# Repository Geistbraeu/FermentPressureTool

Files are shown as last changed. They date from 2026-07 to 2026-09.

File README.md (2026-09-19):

🌐 **English** | [Русский](README.ru.md)

# FermentPressureTool

A device for monitoring and controlling the fermentation process with real-time pressure and temperature measurement.

## 📋 Project Overview

**FermentPressureTool** is an ESP32-based IoT device designed for precise fermentation condition control. It reads pressure and temperature inside a fermentation vessel, uploads data to cloud services, and controls a pressure relief valve.

<p align="center">
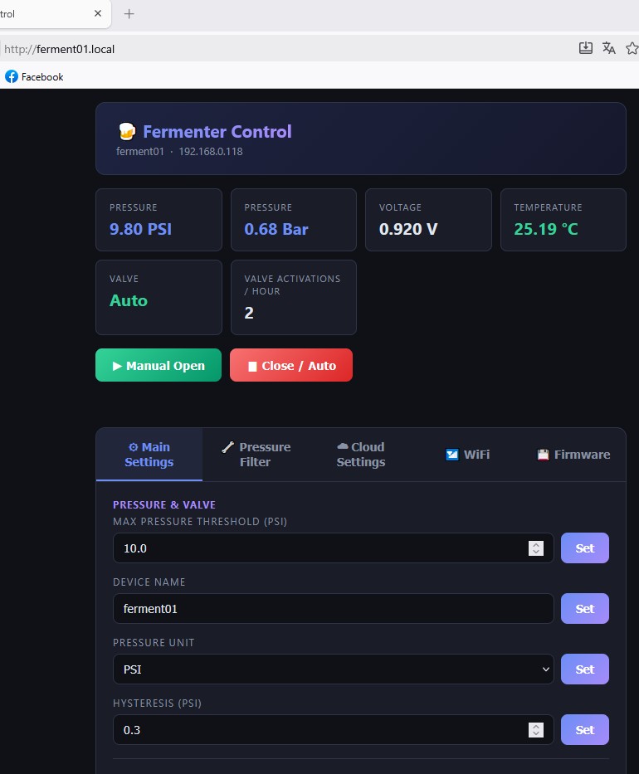
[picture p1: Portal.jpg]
FermentPressureTool web portal
   FermentPressureTool device
</p>

### Key Features

- 📊 **Pressure monitoring** — analog pressure sensor reading via ADC
- 🌡️ **Temperature measurement** — DS18B20 sensor support over OneWire
- 📡 **Cloud integration** — data upload to:
  - **Brewfather** (homebrewing platform)
  - **ThingSpeak** (IoT platform)
  - **Custom HTTP API** (flexible integration)
- 🖥️ **Web interface** — browser-based control and monitoring
- 🔧 **Configuration portal** — WiFi setup without reflashing
- 📱 **OLED display** — alternating pressure and temperature display (SSD1306, 128×64)
- 🤖 **Multithreading** — parallel execution of sensor and network operations
- 💾 **Persistent settings** — stored in Preferences/NVS

## 🛠️ Hardware

### Microcontroller
- **ESP32-DevKit** — WiFi-enabled dual-core microcontroller

### Sensors and Modules
- **Pressure sensor** — analog, connected to `GPIO34` (ADC1_CH6)
- **External ADC (optional)** — ADS1115 on the same I2C bus as the OLED (address `0x48`, pressure input `A0`)
- **Temperature sensor** — DS18B20 (OneWire)
  - DATA: `GPIO4`
  - 4.7 kΩ pull-up resistor required between DATA and VCC
- **OLED display** — SSD1306 128×64 (I2C, address 0x3C)
- **Solenoid valve** — controlled via `GPIO27`

### Connections
- Serial (UART) at 115200 baud for debugging
- CH340 USB-UART converter for programming

### Pressure ADC selection

The web settings provide a choice between the built-in ESP32 ADC and an external ADS1115.
The ESP32 mode keeps the existing voltage divider on `GPIO34`. In ADS1115 mode, connect the
pressure sensor directly to `A0`; the divider is not used because this input supports the
sensor's 0.5-4.5 V signal range. Connect `VDD`, `GND`, `SDA`, and `SCL` to the board and tie
`ADDR` to `GND` for address `0x48`. The ADS1115 and ESP32 must share ground. Do not exceed the
ADS1115 supply voltage or its absolute input limits.

### Recommended settings for external ADC

When using the external ADS1115, the following settings are recommended for stable and responsive
pressure readings:

- Median Sample Count (odd, 3-31): `5`
- Median Sample Delay (ms): `10`
- Update Interval (ms): `50`

These values reduce sensor noise while keeping the UI and pressure control responsive enough for
fermentation monitoring.

When using the external ADS1115, the adaptive filter can be disabled if the ADC already provides a
stable signal and additional smoothing is not needed.

## 📁 Project Structure

```
FermentPressureTool/
├── src/
│   ├── main.cpp                 # Entry point, initialization
│   ├── config.h                 # Central constants (pins, parameters)
│   ├── Settings.h/cpp           # Persistent settings management
│   ├── CloudManager.h/cpp       # Cloud provider coordination
│   ├── ConfigPortal.h/cpp       # WiFi configuration portal
│   ├── web_server.h/cpp         # REST API and web interface
│   ├── RuntimeState.h           # Shared state between cores
│   ├── debug.h                  # Debug macros
│   ├── html_template.h          # Web UI HTML
│   ├── cloud/
│   │   ├── CloudProvider.h      # Base provider interface
│   │   ├── BrewfatherProvider.h/cpp
│   │   ├── ThingSpeakProvider.h/cpp
│   │   └── CustomHTTPProvider.h/cpp
│   └── device/
│       ├── DisplayManager.h/cpp      # OLED display management
│       ├── SensorManager.h/cpp       # Sensor reading (pressure, temperature)
│       └── SolenoidController.h/cpp  # Valve control
├── include/                     # User libraries
├── lib/                         # External libraries
├── test/                        # Tests
├── platformio.ini               # PlatformIO configuration
└── README.md                    # This file
```

## 🔌 Software Components

### CloudManager
Coordinates data upload to cloud platforms. Supports multiple simultaneous providers.

### ConfigPortal
WiFi configuration portal for initial setup and reconfiguration without reflashing.

### SensorManager
- ADC initialization and eFuse-based calibration
- Filtered pressure reading (average of N samples)
- DS18B20 temperature reading over OneWire

### DisplayManager
Manages the SSD1306 OLED display, alternating between pressure and temperature. The switch interval is configurable via the web interface.

### WebServer
REST API for:
- Retrieving current sensor data
- Controlling the valve
- Changing system parameters
- Triggering cloud uploads

### SolenoidController
Controls the solenoid valve for pressure relief.

## 🚀 Getting Started

### Requirements
- **PlatformIO** — embedded build system
- **VS Code** with the PlatformIO extension
- **CH340 driver** — for USB programming

### Dependencies
Declared in `platformio.ini`:
```
adafruit/Adafruit SSD1306 @ ^2.5.9
adafruit/Adafruit GFX Library @ ^1.11.9
adafruit/Adafruit BusIO @ ^1.14.5
paulstoffregen/OneWire @ ^2.3.8
milesburton/DallasTemperature @ ^4.0.4
```

### Build and Flash

1. **Open the project in VS Code**
   ```bash
   code d:\Projects\FermentPressureTool
   ```

2. **Connect the ESP32 via USB**

3. **Select the environment in PlatformIO**
   - Choose `esp32s` from the available environments

4. **Build the project**
   ```bash
   pio run -e esp32s
   ```

5. **Upload the firmware**
   ```bash
   pio run -e esp32s --target upload
   ```

6. **Open the serial monitor**
   ```bash
   pio device monitor -e esp32s
   ```

## ⚙️ Configuration

### Build Flags
Debug flags defined in `platformio.ini`:
- `APP_DEBUG_SERIAL=0` — debug level (0 = disabled)

### Hardware Pins (`src/config.h`)
All pins are defined centrally in `config.h`. Edit the values before building as needed.

### Network Parameters
- **Hostname**: `ferment01` (accessible as `ferment01.local`)
- **Web server port**: 80
- **UART baud rate**: 115200

### Cloud Integrations
Configure API keys and settings via the configuration portal or web interface:
- **Brewfather API Key**
- **ThingSpeak Channel ID and API Key**
- **Custom HTTP URL endpoint**

### OLED and Sensors
- Pressure and temperature are shown alternately on the OLED.
- The switch interval is configurable in the web interface; default is 3 seconds.
- If the temperature sensor is disconnected, only pressure is shown.
- If the pressure sensor is not connected, the display shows `Disconnected` and cloud uploads are skipped.

## 🌐 Cloud Integration

### Brewfather
Integration with the popular homebrewing platform. Sends pressure and temperature data.

### ThingSpeak
IoT platform for data storage and visualization. Supports measurement history and charts.

### Custom HTTP API
Flexible integration with any HTTP API to send data to a custom backend.

## 📊 REST API

### Get Sensor Data
```
GET /api
```

Response:
```json
{
  "pressure": 1.5,
  "temperature": 22.5,
  "voltage": 2.3,
  "pressureConnected": true,
  "tempConnected": true
}
```

### Control the Valve
```
POST /api
Body: cmd=manual_on
```

### Cloud Upload
Cloud uploads are performed automatically in the firmware's main loop and are skipped if the pressure sensor is disconnected.

## 🔄 Multithreading Architecture

The system uses two tasks running on separate ESP32 cores:
- **Core 1**: Sensor operations (reading sensors, valve control)
- **Core 0**: Network operations (WiFi, cloud requests, web server)

Synchronization is handled through the `RuntimeState` structure using semaphores.

## 🐛 Debugging

Debug output is sent to UART when enabled:

```cpp
DBG("Debug message here");
```

View the output in the serial monitor.

---

<div align="center">

  <p>
    <strong>FermentPressureTool</strong><br>
    ESP32-based fermentation pressure and temperature monitor
  </p>

  <p>
    <strong>Version</strong> 1.2.6 · <strong>Updated</strong> 2026-09-20
  </p>

  <p>
    Built with PlatformIO for ESP32 • Pressure control • Cloud integration
  </p>

</div>

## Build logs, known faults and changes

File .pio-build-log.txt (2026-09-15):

Processing esp32s (platform: espressif32 @ ^6.4.0; board: esp32dev; framework: arduino)
--------------------------------------------------------------------------------
Verbose mode can be enabled via `-v, --verbose` option
CONFIGURATION: https://docs.platformio.org/page/boards/espressif32/esp32dev.html
PLATFORM: Espressif 32 (6.13.0) > Espressif ESP32 Dev Module
HARDWARE: ESP32 240MHz, 320KB RAM, 4MB Flash
DEBUG: Current (cmsis-dap) External (cmsis-dap, esp-bridge, esp-prog, iot-bus-jtag, jlink, minimodule, olimex-arm-usb-ocd, olimex-arm-usb-ocd-h, olimex-arm-usb-tiny-h, olimex-jtag-tiny, tumpa)
PACKAGES: 
 - framework-arduinoespressif32 @ 3.20017.241212+sha.dcc1105b 
 - tool-esptoolpy @ 2.41100.0 (4.11.0) 
 - toolchain-xtensa-esp32 @ 8.4.0+2021r2-patch5
LDF: Library Dependency Finder -> https://bit.ly/configure-pio-ldf
LDF Modes: Finder ~ chain, Compatibility ~ soft
Found 39 compatible libraries
Scanning dependencies...
Dependency Graph
|-- Adafruit SSD1306 @ 2.5.17
|-- Adafruit GFX Library @ 1.12.6
|-- Adafruit BusIO @ 1.17.4
|-- Adafruit ADS1X15 @ 2.6.2
|-- OneWire @ 2.3.8
|-- DallasTemperature @ 4.0.6
|-- DNSServer @ 2.0.0
|-- WebServer @ 2.0.0
|-- WiFi @ 2.0.0
|-- Preferences @ 2.0.0
|-- WiFiClientSecure @ 2.0.0
|-- Wire @ 2.0.0
|-- ESPmDNS @ 2.0.0
|-- Update @ 2.0.0
Building in release mode
Compiling .pio\build\esp32s\src\ConfigPortal.cpp.o
Compiling .pio\build\esp32s\src\Settings.cpp.o
Compiling .pio\build\esp32s\src\cloud\BrewfatherProvider.cpp.o
Compiling .pio\build\esp32s\src\cloud\CustomHTTPProvider.cpp.o
Compiling .pio\build\esp32s\src\cloud\ThingSpeakProvider.cpp.o
Compiling .pio\build\esp32s\src\device\DisplayManager.cpp.o
Compiling .pio\build\esp32s\src\device\SensorManager.cpp.o
Compiling .pio\build\esp32s\src\device\SolenoidController.cpp.o
Compiling .pio\build\esp32s\src\main.cpp.o
Compiling .pio\build\esp32s\src\web_server.cpp.o
Building .pio\build\esp32s\bootloader.bin
Generating partitions .pio\build\esp32s\partitions.bin
esptool.py v4.11.0
Creating esp32 image...
Merged 1 ELF section
Successfully created esp32 image.
Compiling .pio\build\esp32s\libf83\Wire\Wire.cpp.o
Compiling .pio\build\esp32s\lib5a8\SPI\SPI.cpp.o
Compiling .pio\build\esp32s\lib5de\Adafruit BusIO\Adafruit_BusIO_Register.cpp.o
Archiving .pio\build\esp32s\lib5a8\libSPI.a
Archiving .pio\build\esp32s\libf83\libWire.a
Compiling .pio\build\esp32s\lib5de\Adafruit BusIO\Adafruit_GenericDevice.cpp.o
Compiling .pio\build\esp32s\lib5de\Adafruit BusIO\Adafruit_I2CDevice.cpp.o
Compiling .pio\build\esp32s\lib5de\Adafruit BusIO\Adafruit_SPIDevice.cpp.o
Compiling .pio\build\esp32s\libc0d\Adafruit GFX Library\Adafruit_GFX.cpp.o
Compiling .pio\build\esp32s\libc0d\Adafruit GFX Library\Adafruit_GrayOLED.cpp.o
Archiving .pio\build\esp32s\lib5de\libAdafruit BusIO.a
Compiling .pio\build\esp32s\libc0d\Adafruit GFX Library\Adafruit_SPITFT.cpp.o
Compiling .pio\build\esp32s\libc0d\Adafruit GFX Library\glcdfont.c.o
Compiling .pio\build\esp32s\lib6a2\Adafruit SSD1306\Adafruit_SSD1306.cpp.o
Compiling .pio\build\esp32s\libc8a\Adafruit ADS1X15\Adafruit_ADS1X15.cpp.o
Compiling .pio\build\esp32s\lib591\OneWire\OneWire.cpp.o
Archiving .pio\build\esp32s\libc0d\libAdafruit GFX Library.a
Compiling .pio\build\esp32s\lib5f8\DallasTemperature\DallasTemperature.cpp.o
Archiving .pio\build\esp32s\lib6a2\libAdafruit SSD1306.a
Compiling .pio\build\esp32s\libef0\WiFi\WiFi.cpp.o
platformio.exe : .pio/libdeps/esp32s/OneWire/OneWire.cpp:599:22: warning: extra
 tokens at end of #undef directive
At line:1 char:79
+ ... ipts\platformio.exe'; & $platformio run *> .pio-build-log.txt; $exitC ...
+                           ~~~~~~~~~~~~~~~~~~~~~~~~~~~~~~~~~~~~~~~
    + CategoryInfo          : NotSpecified: (.pio/libdeps/es...undef directive 
   :String) [], RemoteException
    + FullyQualifiedErrorId : NativeCommandError
 
 #  undef noInterrupts() {portMUX_TYPE mux = portMUX_INITIALIZER_UNLOCKED;portE
NTER_CRITICAL(&mux)
                      ^
.pio/libdeps/esp32s/OneWire/OneWire.cpp:600:20: warning: extra tokens at end of
 #undef directive
 #  undef interrupts() portEXIT_CRITICAL(&mux);}
                    ^
Archiving .pio\build\esp32s\libc8a\libAdafruit ADS1X15.a
Compiling .pio\build\esp32s\libef0\WiFi\WiFiAP.cpp.o
Archiving .pio\build\esp32s\lib591\libOneWire.a
Compiling .pio\build\esp32s\libef0\WiFi\WiFiClient.cpp.o
Archiving .pio\build\esp32s\lib5f8\libDallasTemperature.a
Compiling .pio\build\esp32s\libef0\WiFi\WiFiGeneric.cpp.o
Compiling .pio\build\esp32s\libef0\WiFi\WiFiMulti.cpp.o
Compiling .pio\build\esp32s\libef0\WiFi\WiFiSTA.cpp.o
Compiling .pio\build\esp32s\libef0\WiFi\WiFiScan.cpp.o
Compiling .pio\build\esp32s\libef0\WiFi\WiFiServer.cpp.o
Compiling .pio\build\esp32s\libef0\WiFi\WiFiUdp.cpp.o
Compiling .pio\build\esp32s\lib0c5\DNSServer\DNSServer.cpp.o
Compiling .pio\build\esp32s\lib226\FS\FS.cpp.o
Compiling .pio\build\esp32s\lib226\FS\vfs_api.cpp.o
Archiving .pio\build\esp32s\libef0\libWiFi.a
Archiving .pio\build\esp32s\lib0c5\libDNSServer.a
Compiling .pio\build\esp32s\lib395\WebServer\Parsing.cpp.o
Compiling .pio\build\esp32s\lib395\WebServer\WebServer.cpp.o
Compiling .pio\build\esp32s\lib395\WebServer\detail\mimetable.cpp.o
Compiling .pio\build\esp32s\lib156\Preferences\Preferences.cpp.o
Archiving .pio\build\esp32s\lib226\libFS.a
Compiling .pio\build\esp32s\lib383\WiFiClientSecure\WiFiClientSecure.cpp.o
Compiling .pio\build\esp32s\lib383\WiFiClientSecure\esp_crt_bundle.c.o
Archiving .pio\build\esp32s\lib156\libPreferences.a
Archiving .pio\build\esp32s\lib395\libWebServer.a
Compiling .pio\build\esp32s\lib383\WiFiClientSecure\ssl_client.cpp.o
Compiling .pio\build\esp32s\lib0ca\ESPmDNS\ESPmDNS.cpp.o
Compiling .pio\build\esp32s\lib797\Update\HttpsOTAUpdate.cpp.o
Compiling .pio\build\esp32s\lib797\Update\Updater.cpp.o
Compiling .pio\build\esp32s\FrameworkArduino\Esp.cpp.o
Archiving .pio\build\esp32s\lib383\libWiFiClientSecure.a
Archiving .pio\build\esp32s\lib0ca\libESPmDNS.a
Compiling .pio\build\esp32s\FrameworkArduino\FirmwareMSC.cpp.o
Compiling .pio\build\esp32s\FrameworkArduino\FunctionalInterrupt.cpp.o
Compiling .pio\build\esp32s\FrameworkArduino\HWCDC.cpp.o
Compiling .pio\build\esp32s\FrameworkArduino\HardwareSerial.cpp.o
Archiving .pio\build\esp32s\lib797\libUpdate.a
Compiling .pio\build\esp32s\FrameworkArduino\IPAddress.cpp.o
Compiling .pio\build\esp32s\FrameworkArduino\IPv6Address.cpp.o
Compiling .pio\build\esp32s\FrameworkArduino\MD5Builder.cpp.o
Compiling .pio\build\esp32s\FrameworkArduino\Print.cpp.o
Compiling .pio\build\esp32s\FrameworkArduino\Stream.cpp.o
Compiling .pio\build\esp32s\FrameworkArduino\StreamString.cpp.o
Compiling .pio\build\esp32s\FrameworkArduino\Tone.cpp.o
Compiling .pio\build\esp32s\FrameworkArduino\USB.cpp.o
Compiling .pio\build\esp32s\FrameworkArduino\USBCDC.cpp.o
Compiling .pio\build\esp32s\FrameworkArduino\USBMSC.cpp.o
Compiling .pio\build\esp32s\FrameworkArduino\WMath.cpp.o
Compiling .pio\build\esp32s\FrameworkArduino\WString.cpp.o
Compiling .pio\build\esp32s\FrameworkArduino\base64.cpp.o
Compiling .pio\build\esp32s\FrameworkArduino\cbuf.cpp.o
Compiling .pio\build\esp32s\FrameworkArduino\esp32-hal-adc.c.o
Compiling .pio\build\esp32s\FrameworkArduino\esp32-hal-bt.c.o
Compiling .pio\build\esp32s\FrameworkArduino\esp32-hal-cpu.c.o
Compiling .pio\build\esp32s\FrameworkArduino\esp32-hal-dac.c.o
Compiling .pio\build\esp32s\FrameworkArduino\esp32-hal-gpio.c.o
Compiling .pio\build\esp32s\FrameworkArduino\esp32-hal-i2c-slave.c.o
Compiling .pio\build\esp32s\FrameworkArduino\esp32-hal-i2c.c.o
Compiling .pio\build\esp32s\FrameworkArduino\esp32-hal-ledc.c.o
Compiling .pio\build\esp32s\FrameworkArduino\esp32-hal-matrix.c.o
Compiling .pio\build\esp32s\FrameworkArduino\esp32-hal-misc.c.o
Compiling .pio\build\esp32s\FrameworkArduino\esp32-hal-psram.c.o
Compiling .pio\build\esp32s\FrameworkArduino\esp32-hal-rgb-led.c.o
Compiling .pio\build\esp32s\FrameworkArduino\esp32-hal-rmt.c.o
Compiling .pio\build\esp32s\FrameworkArduino\esp32-hal-sigmadelta.c.o
Compiling .pio\build\esp32s\FrameworkArduino\esp32-hal-spi.c.o
Compiling .pio\build\esp32s\FrameworkArduino\esp32-hal-time.c.o
Compiling .pio\build\esp32s\FrameworkArduino\esp32-hal-timer.c.o
Compiling .pio\build\esp32s\FrameworkArduino\esp32-hal-tinyusb.c.o
Compiling .pio\build\esp32s\FrameworkArduino\esp32-hal-touch.c.o
Compiling .pio\build\esp32s\FrameworkArduino\esp32-hal-uart.c.o
Compiling .pio\build\esp32s\FrameworkArduino\firmware_msc_fat.c.o
Compiling .pio\build\esp32s\FrameworkArduino\libb64\cdecode.c.o
Compiling .pio\build\esp32s\FrameworkArduino\libb64\cencode.c.o
Compiling .pio\build\esp32s\FrameworkArduino\main.cpp.o
Compiling .pio\build\esp32s\FrameworkArduino\stdlib_noniso.c.o
Compiling .pio\build\esp32s\FrameworkArduino\wiring_pulse.c.o
Compiling .pio\build\esp32s\FrameworkArduino\wiring_shift.c.o
Archiving .pio\build\esp32s\libFrameworkArduino.a
Linking .pio\build\esp32s\firmware.elf
Retrieving maximum program size .pio\build\esp32s\firmware.elf
Checking size .pio\build\esp32s\firmware.elf
Advanced Memory Usage is available via "PlatformIO Home > Project Inspect"
RAM:   [==        ]  17.5% (used 57492 bytes from 327680 bytes)
Flash: [========  ]  82.8% (used 1085913 bytes from 1310720 bytes)
Building .pio\build\esp32s\firmware.bin with action:
  "$PYTHONEXE" "$OBJCOPY" --chip esp32 elf2image --flash_mode ${__get_board_flash_mode(__env__)} --flash_freq ${__get_board_f_image(__env__)} --flash_size 4MB --elf-sha256-offset 0xb0 -o $TARGET $SOURCES
Building .pio\build\esp32s\firmware.bin
esptool.py v4.11.0
Creating esp32 image...
Merged 27 ELF sections
Successfully created esp32 image.
_copy_versioned_firmware_bin([".pio\build\esp32s\firmware.bin"], [".pio\build\esp32s\firmware.elf"])
======================== [SUCCESS] Took 130.24 seconds ========================

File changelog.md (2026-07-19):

# Changelog

## 1.2.2 - 2026-07-19

### Fixed
- OLED header now shows the configured device name (`devName`) from settings instead of the compile-time default hostname.
- mDNS now starts with the configured device name, so access via `http://<devName>.local/` works as expected after boot.
- When `devName` is changed in web settings, mDNS is restarted immediately and HTTP service is re-registered, so the new `.local` name applies without reflashing.

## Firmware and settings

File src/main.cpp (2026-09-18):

#include <Arduino.h>
#include <WiFi.h>
#include <Wire.h>
#include <esp_adc_cal.h>
#include <ESPmDNS.h>
#include "config.h"
#include "ConfigPortal.h"
#include "web_server.h"
#include "CloudManager.h"
#include "Settings.h"
#include "RuntimeState.h"
#include "debug.h"
#include "device/DisplayManager.h"
#include "device/SensorManager.h"
#include "device/SolenoidController.h"

// Глобальные переменные для обмена данными между ядрами
RuntimeState runtimeState;

// Прототипы функций
void sensorTask(void *pvParameters);
void networkTask(void *pvParameters);
void processSampledData();

void setup() {
  Serial.begin(NetworkConfig::SERIAL_BAUD_RATE);   
  while (!Serial); 

  Wire.begin();
  DBG("I2C bus initialized");

  // Настройка АЦП и чтение калибровки из eFuse
  sensorManager.initAdc(&runtimeState.adc_chars);

  // Инициализация OLED
  displayManager.init();

  // Инициализация Wi-Fi через ConfigPortal
  ConfigPortal::begin();

  // Инициализация клапана
  solenoidController.init();

  // Инициализация mDNS
  const String mdnsHost = wifiSettings.devName.isEmpty() ? String(NetworkConfig::HOSTNAME) : wifiSettings.devName;
  if (!MDNS.begin(mdnsHost.c_str())) {
    DBG("mDNS ERROR");
  } else {
    DBG("mDNS responder started: " + mdnsHost + ".local");
    MDNS.addService("http", "tcp", NetworkConfig::WEBSERVER_PORT);
  }
 
  // Чтение настроек
  settings.load();

  // Инициализация DS18B20
  sensorManager.initTempSensor(settings.useTempSensor);

  // Создаем мьютекс для защиты общих данных
  runtimeState.dataMutex = xSemaphoreCreateMutex();
  runtimeState.settingsMutex = xSemaphoreCreateMutex();
  if (runtimeState.dataMutex == NULL || runtimeState.settingsMutex == NULL) {
    Serial.println("FATAL: mutex creation failed");
    for (;;) {
      delay(1000);
    }
  }

  // Инициализация веб-сервера
  initWebServer();

  // Задача для чтения сенсора (Core 1)
  xTaskCreatePinnedToCore(
    sensorTask,
    "SensorTask",
    TaskConfig::SENSOR_TASK_STACK_SIZE,
    NULL,
    TaskConfig::SENSOR_TASK_PRIORITY,
    NULL,
    TaskConfig::SENSOR_TASK_CORE
  );

  // Задача для Wi-Fi и облаков (Core 0)
  xTaskCreatePinnedToCore(
    networkTask,
    "NetworkTask",
    TaskConfig::NETWORK_TASK_STACK_SIZE,
    NULL,
    TaskConfig::NETWORK_TASK_PRIORITY,
    NULL,
    TaskConfig::NETWORK_TASK_CORE
  );

  DBG("\n--- Система запущена на двух ядрах ---");
}

void loop() {
  // Пустой цикл, всё работает в задачах FreeRTOS
  vTaskDelete(NULL); 
}

void processSampledData() {
  bool useTempSensor = false;
  float maxPressureThreshold = 0.0f;
  float hysteresis = 0.0f;
  float tempOffset = 0.0f;
  if (xSemaphoreTake(runtimeState.settingsMutex, TaskConfig::MUTEX_TIMEOUT_TICKS) == pdTRUE) {
    useTempSensor = settings.useTempSensor;
    maxPressureThreshold = settings.maxPressureThreshold;
    hysteresis = settings.hysteresis;
    tempOffset = settings.tempOffset;
    xSemaphoreGive(runtimeState.settingsMutex);
  }

  bool isTempConnected = false;
  float t = sensorManager.readTemperature(useTempSensor, tempOffset, &isTempConnected);
  runtimeState.isTempSensorConnected = isTempConnected;

  if (xSemaphoreTake(runtimeState.dataMutex, TaskConfig::MUTEX_TIMEOUT_TICKS) == pdTRUE) {
    if (runtimeState.hasSampledData) {
      runtimeState.currentVoltage = runtimeState.sampledVoltage;
      runtimeState.currentPressure = runtimeState.sampledPressure;
      runtimeState.isPressureSensorConnected = runtimeState.currentVoltage >= SensorConfig::PRESSURE_DISCONNECTED_THRESHOLD_V;
      runtimeState.currentTemp = t;
      runtimeState.isDataReady = true;

        if (runtimeState.manualOverride &&
          (unsigned long)(millis() - runtimeState.manualStartTime) > ControlConfig::MANUAL_OVERRIDE_TIMEOUT_MS) {
          runtimeState.manualOverride = false;
      }

      if (runtimeState.manualOverride) {
          solenoidController.applyState(true, runtimeState.manualOn, runtimeState.currentPressure, maxPressureThreshold, hysteresis);
      } else {
          solenoidController.applyState(false, false, runtimeState.currentPressure, maxPressureThreshold, hysteresis);
      }
    }
    xSemaphoreGive(runtimeState.dataMutex);
  }
}

// --- ЛОГИКА СЕНСОРА (Core 1) ---
void sensorTask(void *pvParameters) {
  unsigned long lastProcessAt = 0;

  for (;;) {
    unsigned int sampleCount = ControlConfig::DEFAULT_MEDIAN_SAMPLE_COUNT;
    unsigned long medianSampleDelayMs = ControlConfig::DEFAULT_MEDIAN_SAMPLE_DELAY_MS;
    unsigned long updateIntervalMs = ControlConfig::DEFAULT_UPDATE_INTERVAL_MS;
    uint8_t pressureAdc = SensorConfig::PRESSURE_ADC_ESP32;
    bool adaptiveFilterEnabled = true;
    float offsetVoltage = SensorConfig::PRESSURE_OFFSET_DEFAULT;
    float adaptiveAlphaMin = ControlConfig::DEFAULT_ADAPTIVE_ALPHA_MIN;
    float adaptiveAlphaMax = ControlConfig::DEFAULT_ADAPTIVE_ALPHA_MAX;
    float adaptiveDeltaRefPsi = ControlConfig::DEFAULT_ADAPTIVE_DELTA_REF_PSI;
    float adaptiveJitterDeadbandPsi = ControlConfig::DEFAULT_ADAPTIVE_JITTER_DEADBAND_PSI;
    if (xSemaphoreTake(runtimeState.settingsMutex, TaskConfig::MUTEX_TIMEOUT_TICKS) == pdTRUE) {
      sampleCount = settings.medianSampleCount;
      medianSampleDelayMs = settings.medianSampleDelayMs;
      updateIntervalMs = settings.updateIntervalMs;
      pressureAdc = settings.pressureAdc;
      adaptiveFilterEnabled = settings.adaptiveFilterEnabled;
      offsetVoltage = settings.offsetVoltage;
      adaptiveAlphaMin = settings.adaptiveAlphaMin;
      adaptiveAlphaMax = settings.adaptiveAlphaMax;
      adaptiveDeltaRefPsi = settings.adaptiveDeltaRefPsi;
      adaptiveJitterDeadbandPsi = settings.adaptiveJitterDeadbandPsi;
      xSemaphoreGive(runtimeState.settingsMutex);
    }

    bool isValveOpen = digitalRead(HardwareConfig::SOLENOID_PIN) == HIGH;
    SensorReading reading = sensorManager.readFilteredPressure(sampleCount,
                                   medianSampleDelayMs,
                                   pressureAdc,
                                   offsetVoltage,
                                   isValveOpen,
                                   adaptiveFilterEnabled,
                                                               adaptiveAlphaMin,
                                                               adaptiveAlphaMax,
                                                               adaptiveDeltaRefPsi,
                                                               adaptiveJitterDeadbandPsi,
                                   &runtimeState.adc_chars);

    // 4. Непрерывно публикуем фильтрованные значения в RuntimeState
    if (xSemaphoreTake(runtimeState.dataMutex, TaskConfig::MUTEX_TIMEOUT_TICKS) == pdTRUE) {
      runtimeState.sampledVoltage = reading.voltage;
      runtimeState.sampledPressure = reading.pressure;
      runtimeState.hasSampledData = true;
      xSemaphoreGive(runtimeState.dataMutex);
    }

    // 5. Периодическая обработка sampled данных по updateIntervalMs
    unsigned long now = millis();
    if (lastProcessAt == 0 || (now - lastProcessAt) >= updateIntervalMs) {
      processSampledData();
      lastProcessAt = now;
    }
  }
}

// --- ЛОГИКА СЕТИ (Core 0) ---
void networkTask(void *pvParameters) {
  initCloud();

  for (;;) {
    float vLocal = 0.0, pLocal = 0.0, tLocal = 0.0;
    uint32_t valveActivationsPerHourLocal = 0;
    bool isTempSensorConnected = false;
    bool isPressureSensorConnected = false;
    bool ready = false;
    int pressureUnit = 0;
    float maxPressureThreshold = 0.0f;
    bool useTempSensor = false;
    unsigned long oledMetricSwitchSeconds = ControlConfig::DEFAULT_OLED_METRIC_SWITCH_SECONDS;

    // Проверка подключения
    if (WiFi.status() != WL_CONNECTED) {
      ConfigPortal::connect();
    }

    // Получаем копию данных и статус готовности
    if (xSemaphoreTake(runtimeState.dataMutex, TaskConfig::MUTEX_TIMEOUT_TICKS) == pdTRUE) {
      vLocal = runtimeState.currentVoltage;
      pLocal = runtimeState.currentPressure;
      tLocal = runtimeState.currentTemp;
      valveActivationsPerHourLocal = runtimeState.valveActivationsPerHour;
      isTempSensorConnected = runtimeState.isTempSensorConnected;
      isPressureSensorConnected = runtimeState.isPressureSensorConnected;
      ready = runtimeState.isDataReady;
      xSemaphoreGive(runtimeState.dataMutex);
    }

    if (xSemaphoreTake(runtimeState.settingsMutex, TaskConfig::MUTEX_TIMEOUT_TICKS) == pdTRUE) {
      pressureUnit = settings.pressureUnit;
      maxPressureThreshold = settings.maxPressureThreshold;
      useTempSensor = settings.useTempSensor;
      oledMetricSwitchSeconds = settings.oledMetricSwitchSeconds;
      xSemaphoreGive(runtimeState.settingsMutex);
    }

    // Обновление дисплея
    String ipStr = "Connecting...";
    if (WiFi.status() == WL_CONNECTED) {
      ipStr = WiFi.localIP().toString();
    }
    float pBar = pLocal * SensorConfig::PSI_TO_BAR;
    displayManager.update(ipStr,
                          vLocal,
                          pBar,
                          pressureUnit,
                          maxPressureThreshold,
                          tLocal,
                          useTempSensor,
                          isTempSensorConnected,
                          oledMetricSwitchSeconds);

    // Выполняем отправку только если данные уже были считаны сенсором
    if (ready && isPressureSensorConnected) {
      sendDataToThingSpeak(vLocal, pLocal, pBar, tLocal, valveActivationsPerHourLocal);
      sendDataToBrewfather(vLocal, pLocal, tLocal, valveActivationsPerHourLocal);
      sendDataViaCustomHTTP(vLocal, pLocal, pBar, tLocal, valveActivationsPerHourLocal);
    }
    unsigned long updateIntervalMs = ControlConfig::DEFAULT_UPDATE_INTERVAL_MS;
    if (xSemaphoreTake(runtimeState.settingsMutex, TaskConfig::MUTEX_TIMEOUT_TICKS) == pdTRUE) {
      updateIntervalMs = settings.updateIntervalMs;
      xSemaphoreGive(runtimeState.settingsMutex);
    }
    vTaskDelay(pdMS_TO_TICKS(updateIntervalMs));
  }
}

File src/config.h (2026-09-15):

#ifndef CONFIG_H
#define CONFIG_H

#include <cstddef>
#include <cstdint>

#include <freertos/FreeRTOS.h>

/**
 * FermentPreassureTool - Centralized Configuration
 * All hardware, sensor, and system constants in one place
 */

// ==================== HARDWARE PINS ====================
namespace HardwareConfig {
  // Solenoid relay control
  constexpr int SOLENOID_PIN = 27;

  // Pressure sensor (ADC)
  constexpr int ADC_PRESSURE_PIN = 34;  // ADC1_CH6

  // Temperature sensor (DS18B20 OneWire)
  constexpr int TEMP_SENSOR_PIN = 4;
}

// ==================== DISPLAY (OLED SSD1306) ====================
namespace DisplayConfig {
  constexpr int SCREEN_WIDTH = 128;
  constexpr int SCREEN_HEIGHT = 64;
  constexpr int OLED_RESET_PIN = -1;
  constexpr uint8_t OLED_I2C_ADDRESS = 0x3C;

  // Display layout coordinates (Y positions)
  constexpr int LAYOUT_Y_HOSTNAME = 0;
  constexpr int LAYOUT_Y_STATUS = 15;
  constexpr int LAYOUT_Y_IP = 20;
  constexpr int LAYOUT_Y_PRESSURE = 28;
  constexpr int LAYOUT_Y_TEMP = 35;
  constexpr int LAYOUT_Y_VOLTAGE = 42;
  constexpr int LAYOUT_Y_MANUAL = 52;

  // Display layout coordinates (X positions)
  constexpr int LAYOUT_X_LEFT = 0;
  constexpr int LAYOUT_X_CENTER = 85;
}

// ==================== SENSOR CALIBRATION ====================
namespace SensorConfig {
  constexpr uint8_t PRESSURE_ADC_ESP32 = 0;
  constexpr uint8_t PRESSURE_ADC_ADS1115 = 1;

  constexpr uint8_t ADS1115_I2C_ADDRESS = 0x48;
  constexpr uint8_t ADS1115_PRESSURE_CHANNEL = 0;

  // DS18B20 disconnect sentinel handling
  constexpr float TEMP_DISCONNECTED_C = -127.0;
  constexpr float PRESSURE_DISCONNECTED_THRESHOLD_V = 0.3f;

  // Pressure sensor calibration
  constexpr float PRESSURE_OFFSET_DEFAULT = 0.515;  // Volts
  constexpr float PRESSURE_VOLTAGE_RANGE = 4.0;      // Volts (4.5V - 0.5V)
  constexpr float PRESSURE_PSI_RANGE = 100.0;        // PSI

  // Voltage divider
  constexpr float ADC_VOLTAGE_DIVIDER = 1.4545455;

  // Unit conversions
  constexpr float PSI_TO_BAR = 0.0689476;

  // ADC settings
  // Note: ADC types don't support constexpr, use direct enum values
  // ADC_ATTEN_DB_12 and ADC_WIDTH_BIT_12 are defined in ESP32 Arduino framework
  constexpr uint32_t ADC_VREF = 1100;  // mV
}

// ==================== SAMPLING & CONTROL ====================
namespace ControlConfig {
  // Median filter
  constexpr unsigned int MAX_MEDIAN_SAMPLES = 31;
  constexpr unsigned int MIN_MEDIAN_SAMPLES = 3;

  // Adaptive pressure filter defaults
  constexpr float DEFAULT_ADAPTIVE_ALPHA_MIN = 0.03f;
  constexpr float DEFAULT_ADAPTIVE_ALPHA_MAX = 0.70f;
  constexpr float DEFAULT_ADAPTIVE_DELTA_REF_PSI = 1.0f;
  constexpr float DEFAULT_ADAPTIVE_JITTER_DEADBAND_PSI = 0.05f;

  // Manual solenoid override timeout
  constexpr unsigned long MANUAL_OVERRIDE_TIMEOUT_MS = 10000;  // 10 seconds

  // Default sampling intervals (configurable via web UI)
  constexpr unsigned long DEFAULT_UPDATE_INTERVAL_MS = 200;
  constexpr unsigned int DEFAULT_MEDIAN_SAMPLE_COUNT = 5;
  constexpr unsigned long DEFAULT_MEDIAN_SAMPLE_DELAY_MS = 10;
  constexpr unsigned long DEFAULT_OLED_METRIC_SWITCH_SECONDS = 3;
}

// ==================== NETWORK & mDNS ====================
namespace NetworkConfig {
  constexpr const char* HOSTNAME = "ferment01";
    // HOSTNAME will be used as: WiFi.setHostname(HOSTNAME) and MDNS.begin(HOSTNAME)
  constexpr int WEBSERVER_PORT = 80;
  constexpr int MDNS_PORT = 53;

  // Serial communication
  constexpr unsigned long SERIAL_BAUD_RATE = 115200;
}

// ==================== CLOUD INTEGRATION ====================
namespace CloudConfig {
  // ThingSpeak
  constexpr const char* THINGSPEAK_SERVER = "api.thingspeak.com";
  constexpr int THINGSPEAK_PORT = 443;  // HTTPS
  constexpr unsigned long THINGSPEAK_DEFAULT_INTERVAL_SEC = 120;

  // Brewfather
  constexpr const char* BREWFATHER_SERVER = "log.brewfather.net";
  constexpr int BREWFATHER_PORT = 443;  // HTTPS
  constexpr unsigned long BREWFATHER_DEFAULT_INTERVAL_MIN = 15;

  // Custom HTTP
  constexpr int CUSTOM_HTTP_PORT_HTTP = 80;
  constexpr int CUSTOM_HTTP_PORT_HTTPS = 443;
  constexpr unsigned long CUSTOM_HTTP_DEFAULT_INTERVAL_SEC = 60;
  constexpr size_t CUSTOM_HTTP_MAX_SERVER_LEN = 64;
  constexpr size_t CUSTOM_HTTP_MAX_PATH_LEN = 128;
  constexpr size_t CUSTOM_HTTP_MAX_BODY_LEN = 512;
  constexpr size_t CUSTOM_HTTP_MAX_KEY_LEN = 128;
}

// ==================== FREERTOS TASK CONFIGURATION ====================
namespace TaskConfig {
  // Sensor task (Core 1)
  constexpr int SENSOR_TASK_STACK_SIZE = 4096;
  constexpr int SENSOR_TASK_PRIORITY = 1;
  constexpr int SENSOR_TASK_CORE = 1;

  // Network task (Core 0)
  constexpr int NETWORK_TASK_STACK_SIZE = 8192;
  constexpr int NETWORK_TASK_PRIORITY = 1;
  constexpr int NETWORK_TASK_CORE = 0;

  // Mutex timeout
  const TickType_t MUTEX_TIMEOUT_TICKS = pdMS_TO_TICKS(100);
}
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

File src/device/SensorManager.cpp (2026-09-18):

#include "device/SensorManager.h"
#include "config.h"
#include "debug.h"
#include <Adafruit_ADS1X15.h>
#include <DallasTemperature.h>
#include <OneWire.h>
#include <Wire.h>
#include <esp_adc_cal.h>
#include <freertos/FreeRTOS.h>
#include <freertos/task.h>
#include <math.h>

static const int sensorPin = HardwareConfig::ADC_PRESSURE_PIN;
static Adafruit_ADS1115 ads1115;
static bool ads1115Available = false;
static unsigned long lastAds1115DebugAt = 0;
static bool ads1115UnavailableReported = false;
static OneWire oneWireBus(HardwareConfig::TEMP_SENSOR_PIN);
static DallasTemperature tempSensor(&oneWireBus);
static bool tempSensorInitialized = false;

SensorManager sensorManager;

void SensorManager::initAdc(esp_adc_cal_characteristics_t* adcChars) {
  analogSetAttenuation(ADC_11db);
  esp_adc_cal_characterize(ADC_UNIT_1, ADC_ATTEN_DB_12, ADC_WIDTH_BIT_12, SensorConfig::ADC_VREF, adcChars);

  DBG("Scanning I2C bus for ADS1115...");
  bool ads1115AddressFound = false;
  for (uint8_t address = 0x03; address <= 0x77; address++) {
    Wire.beginTransmission(address);
    const uint8_t error = Wire.endTransmission();
    if (error == 0) {
      DBGF("I2C device found at 0x%02X\n", address);
      if (address == SensorConfig::ADS1115_I2C_ADDRESS) {
        ads1115AddressFound = true;
      }
    }
  }

  DBGF("ADS1115 probe address=0x%02X present=%s\n",
       SensorConfig::ADS1115_I2C_ADDRESS,
       ads1115AddressFound ? "yes" : "no");
  ads1115Available = ads1115.begin(SensorConfig::ADS1115_I2C_ADDRESS, &Wire);
  if (ads1115Available) {
    ads1115.setGain(GAIN_TWOTHIRDS);
    ads1115.setDataRate(RATE_ADS1115_16SPS);
    DBGF("ADS1115 initialized: address=0x%02X channel=A%d gain=2/3 range=6.144V rate=16SPS\n",
         SensorConfig::ADS1115_I2C_ADDRESS,
         SensorConfig::ADS1115_PRESSURE_CHANNEL);
  } else {
    DBGF("ADS1115 initialization FAILED: address=0x%02X\n", SensorConfig::ADS1115_I2C_ADDRESS);
  }
}

float SensorManager::readEsp32AdcVoltage(const esp_adc_cal_characteristics_t* adcChars) {
  const int rawValue = analogRead(sensorPin);
  const uint32_t voltageMv = esp_adc_cal_raw_to_voltage(rawValue, adcChars);
  return voltageMv / 1000.0f;
}

float SensorManager::readAds1115Voltage() {
  if (!ads1115Available) {
    if (!ads1115UnavailableReported) {
      DBG("ADS1115 read skipped: device is unavailable");
      ads1115UnavailableReported = true;
    }
    return -1.0f;
  }
  const int16_t rawValue = ads1115.readADC_SingleEnded(SensorConfig::ADS1115_PRESSURE_CHANNEL);
  const float voltage = ads1115.computeVolts(rawValue);
  const unsigned long now = millis();
  if (lastAds1115DebugAt == 0 || (unsigned long)(now - lastAds1115DebugAt) >= 1000) {
    DBGF("ADS1115 read: channel=A%d raw=%d voltage=%.4fV\n",
         SensorConfig::ADS1115_PRESSURE_CHANNEL, rawValue, voltage);
    lastAds1115DebugAt = now;
  }
  return voltage;
}

void SensorManager::resetAdaptivePressure() {
  adaptivePressureInitialized = false;
  adaptivePressureFiltered = 0.0f;
  adaptivePreviousError = 0.0f;
  adaptiveTrendCounter = 0;
}

void SensorManager::initTempSensor(bool useTempSensor) {
  (void)useTempSensor;

  if (!tempSensorInitialized) {
    tempSensor.begin();
    tempSensorInitialized = true;
  }
}

float SensorManager::readTemperature(bool isEnabled, float tempOffset, bool* isConnected) {
  if (!isEnabled) {
    if (isConnected != NULL) {
      *isConnected = false;
    }
    return 0.0f;
  }

  if (!tempSensorInitialized) {
    initTempSensor(true);
  }

  if (tempSensor.getDeviceCount() == 0) {
    if (isConnected != NULL) {
      *isConnected = false;
    }
    return 0.0f;
  }

  tempSensor.requestTemperatures();
  float t = tempSensor.getTempCByIndex(0);
  if (t == DEVICE_DISCONNECTED_C || t <= SensorConfig::TEMP_DISCONNECTED_C) {
    DBG("DS18B20 disconnected or read failed");
    if (isConnected != NULL) {
      *isConnected = false;
    }
    return 0.0f;
  }

  if (isConnected != NULL) {
    *isConnected = true;
  }
  return t - tempOffset;
}

SensorReading SensorManager::readFilteredPressure(unsigned int sampleCount, unsigned long sampleDelayMs,
                                                  uint8_t adcSource, float offsetVoltage,
                                                  bool isValveOpen,
                                                  bool adaptiveFilterEnabled,
                                                  float adaptiveAlphaMin,
                                                  float adaptiveAlphaMax,
                                                  float adaptiveDeltaRefPsi,
                                                  float adaptiveJitterDeadbandPsi,
                                                  const esp_adc_cal_characteristics_t* adcChars) {
  float samples[ControlConfig::MAX_MEDIAN_SAMPLES];

  if (!pressureAdcInitialized || activePressureAdc != adcSource) {
    resetAdaptivePressure();
    activePressureAdc = adcSource;
    pressureAdcInitialized = true;
    DBGF("Pressure ADC source: %s\n",
         adcSource == SensorConfig::PRESSURE_ADC_ADS1115 ? "ADS1115" : "ESP32");
  }

  if (adcSource == SensorConfig::PRESSURE_ADC_ADS1115 && !ads1115Available) {
    if (!ads1115UnavailableReported) {
      DBG("Pressure read unavailable: ADS1115 selected but not initialized");
      ads1115UnavailableReported = true;
    }
    SensorReading unavailableReading;
    return unavailableReading;
  }

  if (sampleCount < ControlConfig::MIN_MEDIAN_SAMPLES) {
    sampleCount = ControlConfig::MIN_MEDIAN_SAMPLES;
  }
  if (sampleCount > ControlConfig::MAX_MEDIAN_SAMPLES) {
    sampleCount = ControlConfig::MAX_MEDIAN_SAMPLES;
  }
  if ((sampleCount % 2) == 0) {
    sampleCount++;
    if (sampleCount > ControlConfig::MAX_MEDIAN_SAMPLES) {
      sampleCount = ControlConfig::MAX_MEDIAN_SAMPLES;
    }
  }

  for (unsigned int i = 0; i < sampleCount; i++) {
    samples[i] = adcSource == SensorConfig::PRESSURE_ADC_ESP32
                     ? readEsp32AdcVoltage(adcChars) * SensorConfig::ADC_VOLTAGE_DIVIDER
                     : readAds1115Voltage();
    vTaskDelay(pdMS_TO_TICKS(sampleDelayMs));
  }

  for (unsigned int i = 0; i < sampleCount - 1; i++) {
    for (unsigned int j = 0; j < sampleCount - i - 1; j++) {
      if (samples[j] > samples[j + 1]) {
        float temp = samples[j];
        samples[j] = samples[j + 1];
        samples[j + 1] = temp;
      }
    }
  }
  const float sensorVoltage = samples[sampleCount / 2];

  float pressure = 0.0f;
  if (sensorVoltage > offsetVoltage) {
    pressure = (sensorVoltage - offsetVoltage) * SensorConfig::PRESSURE_PSI_RANGE / SensorConfig::PRESSURE_VOLTAGE_RANGE;
  }
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

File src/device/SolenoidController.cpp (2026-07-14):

#include "device/SolenoidController.h"
#include <Arduino.h>
#include <string.h>
#include "config.h"
#include "debug.h"
#include "RuntimeState.h"

SolenoidController solenoidController;
extern RuntimeState runtimeState;

static constexpr uint32_t kValveActivationWindowSeconds = 3600U;

static void trackValveActivationCycle(bool valveOpen) {
  const uint32_t nowSecond = millis() / 1000U;

  if (runtimeState.valveActivationLastSecond == 0U) {
    runtimeState.valveActivationLastSecond = nowSecond;
  }

  const uint32_t elapsedSeconds = nowSecond - runtimeState.valveActivationLastSecond;
  if (elapsedSeconds >= kValveActivationWindowSeconds) {
    memset(runtimeState.valveActivationBuckets, 0, sizeof(runtimeState.valveActivationBuckets));
    runtimeState.valveActivationsPerHour = 0U;
  } else if (elapsedSeconds > 0U) {
    for (uint32_t step = 1U; step <= elapsedSeconds; ++step) {
      const uint32_t staleIndex = (runtimeState.valveActivationLastSecond + step) % kValveActivationWindowSeconds;
      runtimeState.valveActivationsPerHour -= runtimeState.valveActivationBuckets[staleIndex];
      runtimeState.valveActivationBuckets[staleIndex] = 0;
    }
  }

  runtimeState.valveActivationLastSecond = nowSecond;

  if (valveOpen) {
    const uint32_t currentIndex = nowSecond % kValveActivationWindowSeconds;
    ++runtimeState.valveActivationBuckets[currentIndex];
    ++runtimeState.valveActivationsPerHour;
  }
}

void SolenoidController::init() {
  pinMode(HardwareConfig::SOLENOID_PIN, OUTPUT);
  digitalWrite(HardwareConfig::SOLENOID_PIN, LOW);
}

void SolenoidController::applyState(bool manualOverride, bool manualOn, float currentPressure, float maxPressureThreshold, float hysteresis) {
  static bool initialized = false;
  static bool lastManualOverride = false;
  static bool lastValveOpen = false;

  if (manualOverride) {
    bool valveOpen = manualOn;
    digitalWrite(HardwareConfig::SOLENOID_PIN, valveOpen ? HIGH : LOW);
    if (!initialized || !lastManualOverride || valveOpen != lastValveOpen) {
      DBGF("[Valve] MANUAL %s\n", valveOpen ? "OPEN" : "CLOSED");
    }
    initialized = true;
    lastManualOverride = true;
    lastValveOpen = valveOpen;
    trackValveActivationCycle(valveOpen);
    return;
  }

  bool valveOpen = digitalRead(HardwareConfig::SOLENOID_PIN) == HIGH;
  bool desiredValveOpen = valveOpen;
  if (currentPressure > maxPressureThreshold) {
    desiredValveOpen = true;
  } else if (currentPressure < (maxPressureThreshold - hysteresis)) {
    desiredValveOpen = false;
  }

  if (desiredValveOpen != valveOpen) {
    digitalWrite(HardwareConfig::SOLENOID_PIN, desiredValveOpen ? HIGH : LOW);
    valveOpen = desiredValveOpen;
  }

  if (!initialized || lastManualOverride || valveOpen != lastValveOpen) {
    DBGF("[Valve] AUTO %s (P=%.2f, threshold=%.2f, hysteresis=%.2f)\n",
         valveOpen ? "OPEN" : "CLOSED",
         currentPressure,
         maxPressureThreshold,
         hysteresis);
  }

  initialized = true;
  lastManualOverride = false;
  lastValveOpen = valveOpen;
  trackValveActivationCycle(valveOpen);
}

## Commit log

2026-06-13 moved to esp32
2026-06-13 Add PT100 temperature sensor support with MAX31865 and update OLED UI
2026-06-17 Disable MAX31865 temperature reading
2026-06-17 Implement web server, mDNS, and NVS settings for pressure and voltage offset
2026-06-17 Implement manual valve control with countdown timer and web UI
2026-06-17 Finalize valve control, web server settings, and mDNS implementation
2026-06-20 Add median sample count and delay settings with web interface support
2026-06-20 Refactor settings management: update sensor interval to update interval, add sampled data handling, and adjust web server API
2026-06-20 Refactor HTML generation to improve live data updates and enhance valve state management
2026-07-08 Refine ADC voltage divider precision and update mutex timeout type
2026-07-14 Update temperature sensor from MAX31865 to DS18B20 and adjust related configurations
2026-07-14 Add valve activation tracking and update related data transmission methods
2026-07-15 Add adaptive pressure filtering based on valve state
2026-07-15 Add adaptive pressure filter settings and validation methods
2026-07-15 Add OLED metric switch functionality and validation
    - Introduced oledMetricSwitchSeconds to manage OLED display update intervals.
    - Updated DisplayManager to toggle temperature display based on the new interval.
    - Enhanced settings management to include OLED switch interval with validation.
    - Modified HTML output to allow user configuration of OLED switch interval.
    - Updated runtime and settings snapshots to include pressure sensor connection status.
2026-07-15 Update README.md to enhance OLED display functionality and clarify sensor integration details
2026-07-19 Update version to 1.2.2 and enhance device name handling in OLED display and mDNS
2026-07-19 Added Hardware Schema
    [fermentpressure.fzz]
2026-09-15 migrate to ads1115
    [oled&sensor block.fzz]
2026-09-18 Refactor code structure for improved readability and maintainability
    [fermentpressure_v3.fzz, oled&sensor block.fzz]
2026-09-19 Update version to 1.2.5 and remove battery voltage from JSON payload in BrewfatherProvider
    [oled&sensor block.fzz]
2026-09-19 Update version to 1.2.6 and adjust voltage precision in JSON response
2026-10-22 Update temperature source options and version to 1.2.7 in documentation and code
2026-10-22 feat: configure pressure sensor range and bump version to 1.2.8
